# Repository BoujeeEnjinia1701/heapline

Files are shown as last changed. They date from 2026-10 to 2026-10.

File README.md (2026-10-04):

# HeapLine

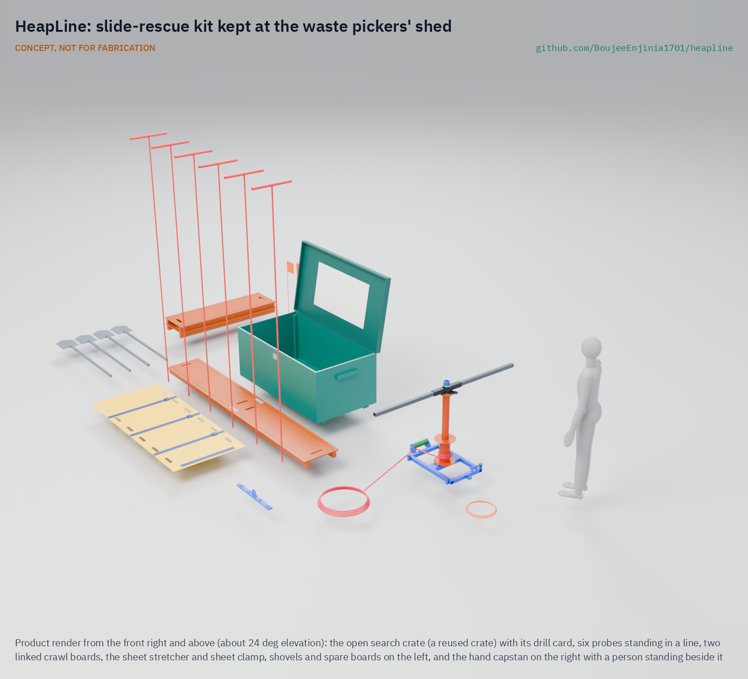
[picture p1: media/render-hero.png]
HeapLine: slide-rescue kit kept at the waste pickers' shed


     

**Area:** Situational field hardware · **TRL:** 3 of 9 (proof of concept on paper; constructable design) · **Value-engineering target:** USD 1,800; estimated parts cost USD 1,374 for the host site (USD 827 for each other site) · **Difficulty:** 3 of 5

Keeps a slide-rescue kit at the pickers' shed so they can search, probe and dig safely in the first minutes.

> CONCEPT, NOT FOR FABRICATION. HeapLine is a TRL 3 design on paper: it has not been built or tested.

## Concept rationale

HeapLine is a slide-rescue kit kept in a locked box at the waste pickers' shed or cooperative office. It holds probes, crawl boards, shovels, a hand capstan and a sheet stretcher. After a slide, pickers carry it out, post a lookout on the slope above, probe along the likely burial line, dig from crawl boards so they do not sink or trigger another slide, and move casualties out on the stretcher. A plain stop rule, printed on the lid, tells everyone when to pull back.

The model is companion rescue in avalanches, where survivors on the spot search at once rather than waiting for help, because survival falls quickly with burial time. The kit is cheap and made from common materials so cooperatives, municipalities and NGOs can stock every site. It is published as an open engineering reference, not certified rescue equipment, and it never replaces making the dumpsite itself safe.

## Burning platform

Dumpsite slides kill people who live and work on and beside the waste. The March 2017 landslide at Koshe in Addis Ababa killed 116 people ([UN-Habitat, 2019](https://unhabitat.org/news/05-jul-2019/after-the-tragic-landslide-that-killed-116-koshe-landfill-in-addis-ababa-is-safer)), at a site where 500 to 600 waste pickers worked every day ([IDS, 2017](https://www.ids.ac.uk/opinions/recognise-informal-waste-pickers-to-avoid-future-disasters-like-koshe/)). On 9 August 2024, after heavy rain, the Kiteezi landfill in Kampala collapsed onto homes; 35 bodies had been recovered by 16 August ([Wikipedia](https://en.wikipedia.org/wiki/Kiteezi_Landfill)), dozens were still missing and about 1,000 people were displaced ([StrongMinds](https://strongminds.org/kiteezi-landslide-highlights-urgent-need-for-mental-health-care-in-climate-disaster-responses/)). About 800 to 1,000 people scavenged at Kiteezi ([Wikipedia](https://en.wikipedia.org/wiki/Kiteezi_Landfill)).

These are not isolated events: the same account of Kiteezi lists failures at Naucalpan in Mexico in 2023, Meethotamulla in Sri Lanka and Koshe in 2017, and Guatemala City in 2008 ([Eos Landslide Blog, 2024](https://eos.org/thelandslideblog/kiteezi-1)). More than 15 million people are reported to live and work in communities that depend on dumpsites, and that is thought to be an underestimate ([International Samaritan, citing ISWA](https://intsam.org/about-garbage-dump-communities/)). Reporting on Kiteezi described rescue efforts as rudimentary ([The Independent, Uganda, 2024](https://www.independent.co.ug/cover-story-lets-not-waste-kiteezi-garbage-tragedy/)).

## Where it could be used

### By industry

| Industry | Use |
| --- | --- |
| Informal waste picking and recycling cooperatives | Kit and drill kept at the shed for the first minutes after a slide |
| Municipal solid waste management | A low-cost emergency measure for open dumps awaiting closure or rehabilitation |
| Disaster risk reduction and civil protection | Community first-responder training for dumpsite neighbourhoods |
| Humanitarian and development NGOs | Stocking kits and training at sites where people live on or beside waste |
| Small quarries, spoil heaps and mine waste | The same probe, board and dig method on other unstable heaps |

### By country or region

| Country or region | Why it matters there |
| --- | --- |
| Ethiopia | The 2017 Koshe landslide killed 116 people ([UN-Habitat, 2019](https://unhabitat.org/news/05-jul-2019/after-the-tragic-landslide-that-killed-116-koshe-landfill-in-addis-ababa-is-safer)). |
| Uganda | The 2024 Kiteezi collapse killed at least 35 people and displaced about 1,000 ([StrongMinds](https://strongminds.org/kiteezi-landslide-highlights-urgent-need-for-mental-health-care-in-climate-disaster-responses/)). |
| Sri Lanka and Mexico | Dumpsite landslides at Meethotamulla (2017) and Naucalpan (2023) show the hazard outside Africa ([Eos Landslide Blog, 2024](https://eos.org/thelandslideblog/kiteezi-1)). |
| Guatemala | A dumpsite failure in Guatemala City in 2008 ([Eos](https://eos.org/thelandslideblog/kiteezi-1)), at a site where about 2,000 recyclers work ([International Samaritan](https://intsam.org/about-garbage-dump-communities/)). |
| Jamaica | About 3,000 recyclers work at the Riverton City dump in Kingston ([International Samaritan](https://intsam.org/about-garbage-dump-communities/)). |

## What sparked the idea

The spark was the Kiteezi collapse in Kampala on 9 August 2024. After heavy rain the waste slope failed onto homes, killing at least 35 people, with dozens more missing ([StrongMinds](https://strongminds.org/kiteezi-landslide-highlights-urgent-need-for-mental-health-care-in-climate-disaster-responses/)), and coverage described rescue efforts as rudimentary ([The Independent, Uganda, 2024](https://www.independent.co.ug/cover-story-lets-not-waste-kiteezi-garbage-tragedy/)). A 2021 study had already recommended closing the site ([Eos Landslide Blog](https://eos.org/thelandslideblog/kiteezi-1)). The people closest to the victims were neighbours and pickers who knew the site, and they had nothing to dig with that was safer than their hands.

## Problem

When a dumpsite slope fails, waste pickers and neighbours are the first on the scene and start digging with their hands, on unstable waste, with no tools and no plan. They need a simple rescue kit and drill kept on site for the first minutes.

Full problem statement: [docs/01-problem.md](docs/01-problem.md)

## Concept

A slide-rescue kit kept at the waste pickers' shed (probes, crawl boards, shovels, capstan and sheet stretcher); after a dumpsite slide, pickers carry it out, probe and dig for buried people in the first minutes under a lookout and a clear stop rule.

Full design precis: [docs/02-concept.md](docs/02-concept.md) · Requirements: [docs/03-requirements.md](docs/03-requirements.md) · Calculations: [docs/04-calcs/01-sizing.md](docs/04-calcs/01-sizing.md) · Prototype build plan: [docs/05-build-plan.md](docs/05-build-plan.md) · Design decisions: [docs/06-design-decisions.md](docs/06-design-decisions.md) · 3D viewer: [media/viewer.html](media/viewer.html)

On paper (HPL-CAL-001): the first probe line starts about 4.6 minutes after the alarm; the hand capstan pulls 5 kN with four people at 114 N each, and a shear pin caps the rope at about 6.4 kN; with 18 mm probe tips, one person reaches 2.6 m in loosened debris and two people in stiffer debris; crawl boards sink 44 mm under a kneeling searcher. Following Amish's decisions of 2026-10-03, four people haul the stretcher on debris, the kit goes out in two waves of about 22 kg a person, and one capstan set is shared by neighbouring sites, so each site's search kit costs USD 827 against the restated USD 850 (R9). How far apart sharing sites may be is open in [docs/06-design-decisions.md](docs/06-design-decisions.md).

## Key components

- Search crate: a reused timber crate refitted on skids at every site, combination padlock, drill card and stop rule on the lid; the shared capstan set has its own crate at the host site
- Probes: six, each three 1 m steel sections on spigots with a blunt 18 mm tip
- Crawl boards: four plywood boards on battens, linked end to end
- Shovels: four, long handled
- Hand capstan: pumped friction capstan with a drive ratchet, two holding pawls and a shear pin; 14 mm rope, sling to a sound anchor, sheet clamp
- Sheet stretcher: roll-up 2 mm HDPE sheet with straps
- Lookout kit: whistles, vests, marker wands, safe-zone sign
- Lighting and PPE: AA head lamps (no lithium cells); gloves, boots, masks and glasses from the cooperative's stock

## Building the prototype

The build plan takes a capable maker from plywood, steel tube, plate and HDPE sheet to one complete site kit, with a making sketch for each of the sixteen made components, close-ups of the eleven joints that need one and fifteen illustrated steps. The boards and box are glued and screwed; the capstan, probes and clamp are cut, welded and profile cut; the rope, lifting gear, shovels and protective equipment are bought. It is a plan, not yet built; building and testing to it is TRL 4 work. See [docs/05-build-plan.md](docs/05-build-plan.md).

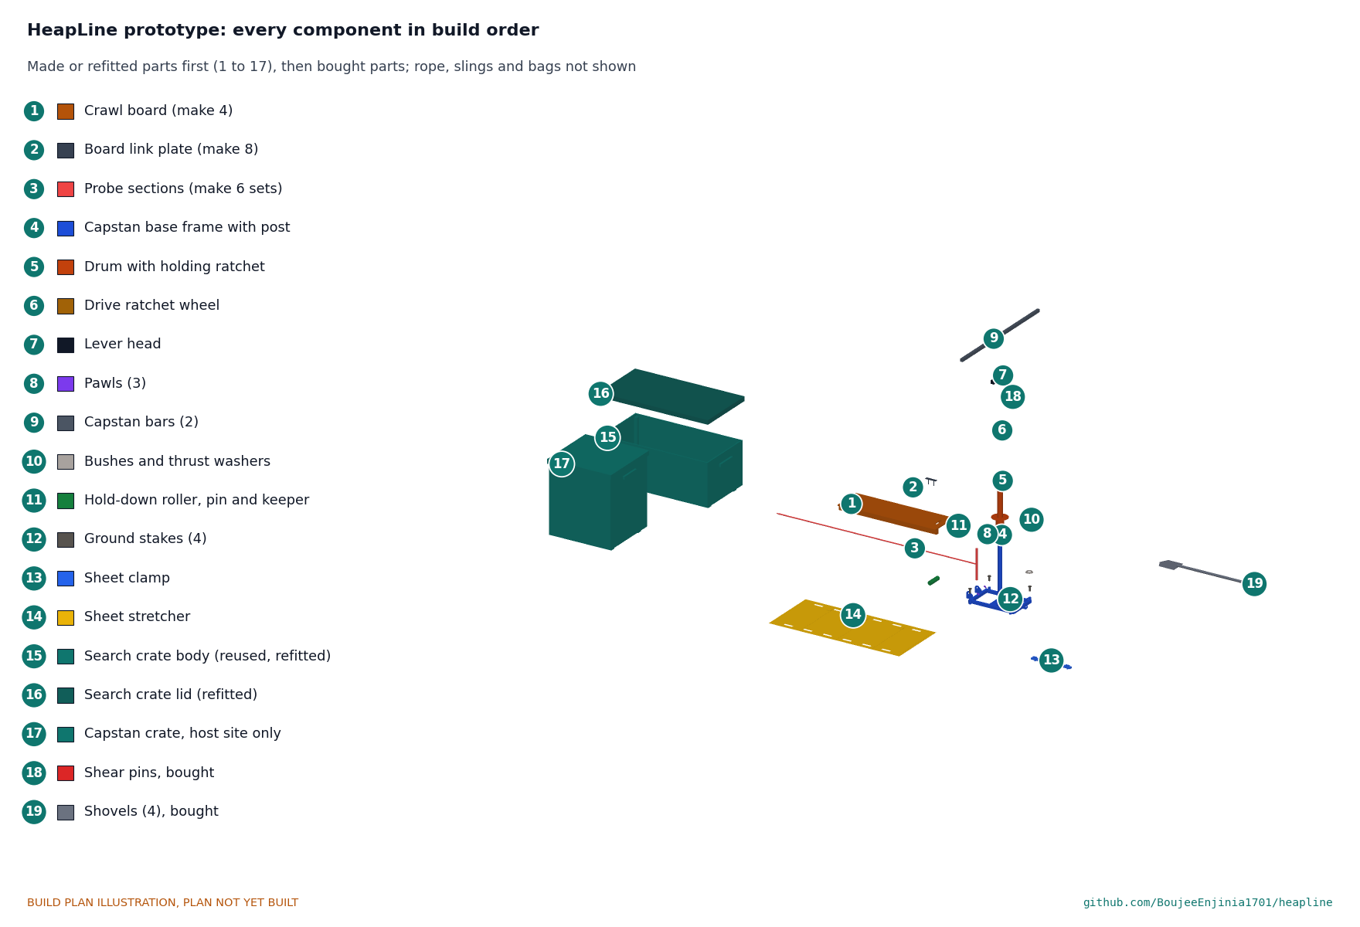
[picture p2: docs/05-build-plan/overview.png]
Every component of the prototype, pulled apart and numbered in build order


## Safety

> Rescue on unstable ground: published as an open engineering reference, not certified rescue equipment.
>
> A second slide can bury the rescuers. Never search without a lookout, and obey the stop rule every time.
>
> Call the fire service and emergency services at once; the kit is for the minutes before they arrive.
>
> Landfill gas can be flammable or toxic; no naked flames or smoking at the search.
>
> Sharp waste and infection risk: gloves and boots are part of the kit.
>
> The kit does not make a dumpsite safe; it must not be used to argue against closure or rehabilitation.
>
> The capstan rope stores energy: nobody in the line of a loaded rope, never lift or pull on a person, and fit only the specified 6 mm S275 shear pin.
>
> This design is published as an open engineering reference. It is not certified equipment.

## Repository layout

| Folder | Contents |
| --- | --- |
| `docs/` | Problem, concept, requirements, calculations and design decisions |
| `cad/src/` | build123d Python source, the source of truth for all geometry |
| `cad/step/`, `cad/stl/` | Exported models for FreeCAD, other CAD tools and printing |
| `cad/drawings/` | 2D sketches and dimensioned drawings |
| `bom/` | Bill of materials |
| `electronics/` | KiCad schematics and PCB layouts |
| `firmware/` | Microcontroller code |
| `media/` | Renders, perspectives and photos |
| `build-log/` | Dated prototyping notes |

## Documentation

Controlled documents follow the portfolio [documentation standard](.kit/STANDARDS.md). Each carries a document ID (HPL-PRC-001 for the precis), a version and a revision history. Branded PDFs are built with `python .kit/render.py` and attached to GitHub Releases when a document is tagged, for example `HPL-PRC-001/v1.0`.

## Credits

Designed by Amish Chadha at Design Molecule Labs. See [CONTRIBUTORS.md](CONTRIBUTORS.md) for roles. To cite this design, use [CITATION.cff](CITATION.cff) (GitHub shows it as "Cite this repository").

AI assistance (Claude) was used to accelerate prototype documentation and first-pass research. Design direction and all decisions are Amish Chadha's, recorded in this repository's decision records (`docs/decisions/`).

## Licenses

- **Hardware** (CAD, drawings, BOM, electronics): [CERN-OHL-S v2](LICENSE)
- **Software** (firmware, scripts, notebooks): [MIT](LICENSE-SOFTWARE)

A project of the [Design Molecule](https://designmolecule.com) lab.

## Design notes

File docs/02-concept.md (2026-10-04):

---
doc_id: HPL-PRC-001
title: HeapLine design precis
project: HeapLine
doc_type: Precis
version: "0.4"
status: Draft
date: '2026-10-03'
author: Amish Chadha
license: CERN-OHL-S-2.0
revisions:
- version: "0.1"
  date: '2026-09-30'
  author: Amish Chadha
  change: Initial scaffold
- version: "0.2"
  date: '2026-10-03'
  author: Amish Chadha
  change: TRL 2 precis; how it works, components, key design choices (HPL-DDR-001), first-order numbers, stop rule, safety
- version: "0.3"
  date: '2026-10-03'
  author: Amish Chadha
  change: TRL 3 figures from HPL-CAL-001 and the constructable design (HPL-DDR-002); pumped friction capstan with shear pin and holding pawls, sectional probes, linked crawl boards, enlarged site box
- version: "0.4"
  date: '2026-10-03'
  author: Amish Chadha
  change: "Amish's requirement decisions 20A, 21A, 22A and 23C (HPL-DDR-003): 18 mm probe tips; four haulers on debris; two carrying waves; reused search crate at every site, one capstan set shared by neighbouring sites, PPE from the cooperative"
---

# HeapLine design precis

Keeps a slide-rescue kit at the pickers' shed so they can search, probe and dig safely in the first minutes.

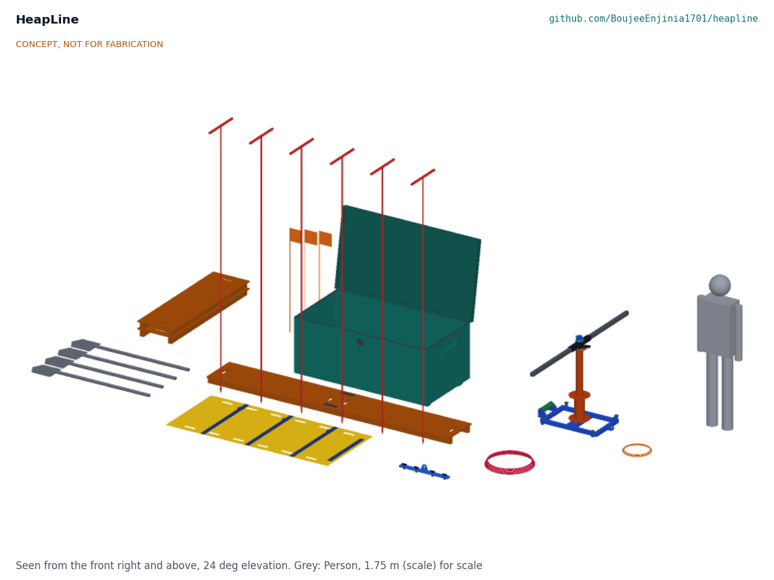
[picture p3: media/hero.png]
Figure 1. HeapLine kit laid out beside its search crate


*Figure 1. Concept render: the open search crate, six probes standing in a line, two linked crawl boards with the sheet stretcher and sheet clamp in front, shovels and spare boards on the left, and the hand capstan on the right with a 1.75 m person beside it.*

## Summary

HeapLine is a slide-rescue kit kept in a locked, reused crate at the waste pickers' shed. The search crate holds six sectional steel probes, four linked crawl boards, four shovels, a roll-up sheet stretcher, a lookout kit, lamps and the cooperative's protective equipment, with the drill card and stop rule printed on the lid. One hand capstan set, with its rope, anchor sling and sheet clamp, is shared by neighbouring sites and kept in its own crate at the host site. After a slide, four people carry the search kit out, post a lookout, lay boards onto the debris, probe in a line and dig from the boards; a second group of three brings the capstan to pull sheeting and timber off the dig from firm ground. On paper the first probe line starts 4.6 minutes after the alarm, the capstan gives 5 kN with four people at 114 N each, each site's search kit costs USD 827 and the shared capstan set USD 547 (HPL-CAL-001). It is an open engineering reference, not certified rescue equipment, and it never replaces making the dumpsite safe.

## How it works

1. **Alarm and lookout.** The first person at a slide raises the alarm and calls the fire service and emergency services. Someone runs to the shed, opens the combination padlock and hands out the search kit. Before anyone steps onto the debris, a lookout in a vest stands on stable ground to the side of the slide with a whistle and watches the slope above.
2. **Boards.** Searchers lay crawl boards from firm ground onto the debris and join them end to end with link plates. They kneel and walk only on the boards, which spread their weight and bridge voids.
3. **Probe line.** Up to six searchers stand on the boards about 0.5 m apart and push probes straight down, three 1 m sections joined on spigots, 2.6 m usable. A strike that feels soft and gives is marked with a flagged wand.
4. **Dig.** Searchers dig at each mark from the boards with long-handled shovels, from the downslope side, keeping a board between them and the hole's edge.
5. **Capstan.** Where sheeting, timber or heavy debris lies over a mark, a second group of three, who have brought the capstan set from the host site, sets the capstan on firm ground, stakes it and slings it to a sound tree, vehicle or column. The sheet clamp or a choker sling goes on the load, the rope runs to the capstan, and four people pump the two bars through quarter turns while a fifth tails the rope. Two pawls hold the drum whenever the bars stop; a 6 mm shear pin releases at about 6.4 kN so the rope, the capstan and the anchor are never overloaded. The capstan only pulls loads sideways away from the dig; it never lifts and never pulls on a person.
6. **Move the casualty.** The casualty is slid onto the sheet stretcher, strapped, and pulled back along the boards to a pickup point on firm ground: four haulers whenever it crosses debris, two only along the boards.
7. **Stop rule.** On any stop signal everyone leaves the debris along the boards to the marked safe zone, to the side of the slide path and never below it, and waits for the lookout's all clear or for the formal responders.

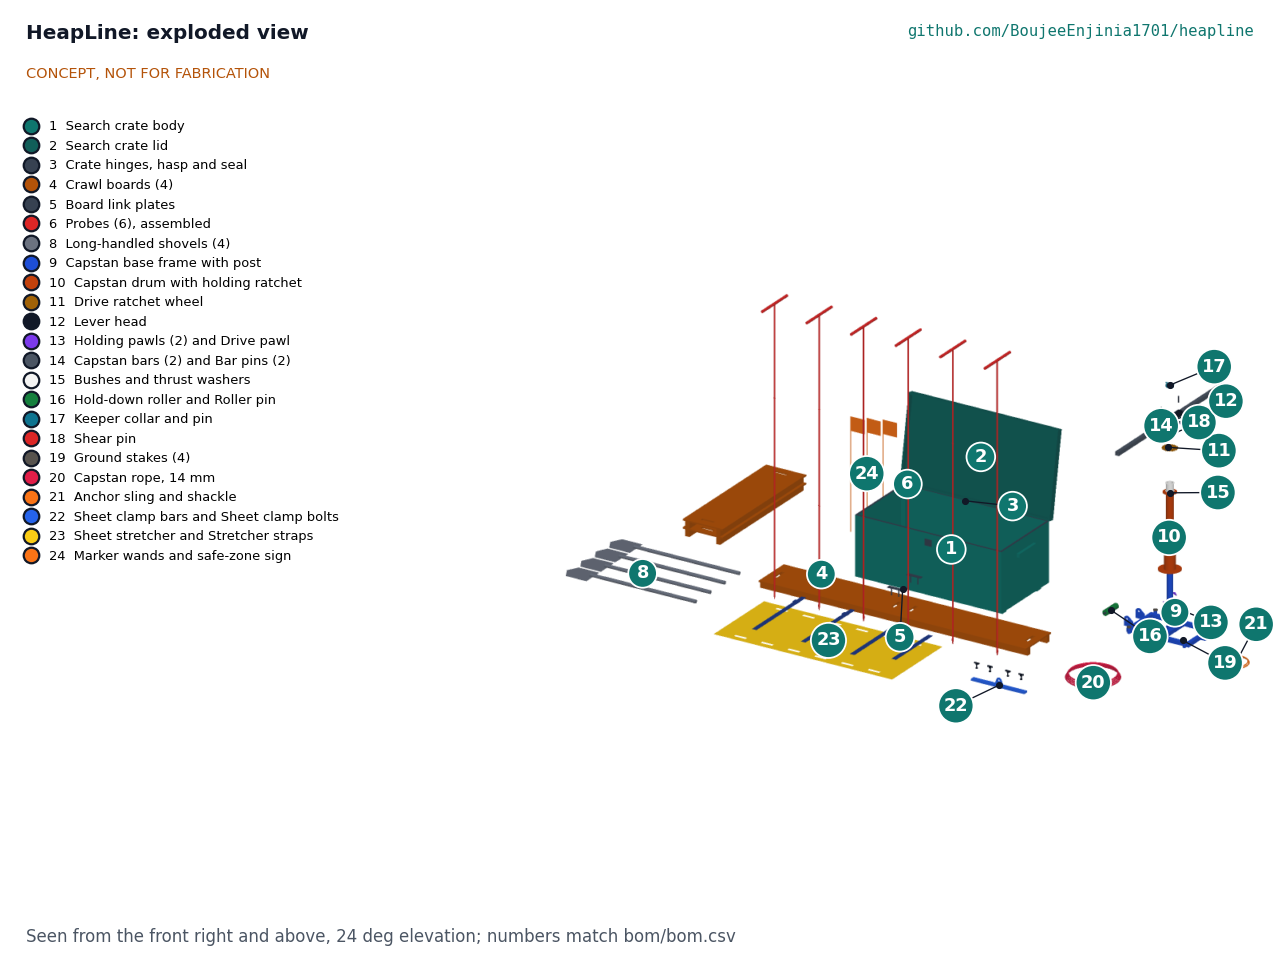
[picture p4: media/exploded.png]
Figure 2. Exploded view with BOM callouts


*Figure 2. Exploded view; the capstan parts are lifted off their post. Numbers are bill of materials lines.*

## Components

*Table 1. Main components (line numbers from `bom/bom.csv`).*

| BOM | Component | What it is |
| --- | --- | --- |
| 1, 2, 3 | Search crate | A reused timber crate (or bought job box), outside about 1640 x 860 x 640 mm, refitted on skids with a skirted lid over a seal, three strap hinges, hasp and combination padlock; stays at the shed |
| 31 | Capstan crate | A second reused crate at the host site only, outside about 940 x 900 x 1060 mm, for the shared capstan set |
| 4, 5 | Crawl boards | Four 1500 x 450 mm boards, 15 mm plywood on two 45 x 70 mm battens, 9.7 kg each; joined by link plates with two 12 mm pins |
| 6, 7 | Probes | Six probes, each three 1 m sections of 16 x 2.0 mm steel tube on spigots with R-clips, an 18 mm tip rounded to 3 mm and a 450 mm T handle; 3.07 m, 3.07 kg |
| 8 | Shovels | Four long-handled round-point shovels |
| 9 to 18 | Hand capstan | Base frame with a fixed post; drum turning on acetal bushes with a 24-tooth holding ring and two pawls; drive ratchet joined to the drum only by the 6 mm shear pin; lever head with a drive pawl and two bar sockets; two 900 mm bars; hold-down roller; keeper collar |
| 19 | Stakes | Four 25 mm stakes and a club hammer; they stop the frame turning, they are not the anchor |
| 20, 21 | Rope and lifting gear | 30 m of 14 mm polyester double braid (40 kN); two 2,000 kg round slings and three shackles |
| 22 | Sheet clamp | Two 50 x 8 mm flats with four wing bolts and a shackle lug; grips plastic sheeting |
| 23 | Sheet stretcher | 2 mm HDPE sheet 2000 x 900 mm with hand slots and three straps; rolls to 250 mm |
| 24 to 27 | Lookout kit, lighting, PPE, drill card | Whistles, vests, marker wands, safe-zone sign; AA lamps; gloves, boots, masks, glasses from the cooperative's stock; drill card and stop rule on the lid |

## Key design choices

Decided under Amish's pre-approvals of 2026-10-03 (HPL-DDR-001 and HPL-DDR-002) and by his requirement decisions of 2026-10-03 (HPL-DDR-003):

- **A pumped friction capstan.** The crew stands still and pumps two bars through a quarter turn; a drive ratchet turns the drum and two holding pawls keep it from running back. Nobody walks round it or steps over a rope at knee height, and the rope leaves under a roller 38 mm above the ground, level with the anchor sling, so it cannot tip.
- **A shear pin as the weakest link.** The rope, capstan, slings and anchor are all sized on 8 kN; the pin releases between 5.1 and 7.6 kN.
- **Sound anchors only.** A round sling to a tree, a parked vehicle or a structural column; never waste, never stakes alone. No sound anchor, no capstan.
- **Push, never drive, the probes.** A blunt tip and no hammer, so a probe cannot injure a buried person.
- **No lithium cells and no gas detector in the box.** Both would need upkeep the kit cannot assume; the rules cover the gap.
- **Everything packs.** The search crate and the capstan crate are sized so every item fits without clashes, the capstan standing assembled with its bars off (checked in the model).
- **A small, blunt probe tip.** 18 mm, 1 mm proud of the tube each side, so two people reach full depth in stiffer debris.
- **Two waves and four haulers.** The search kit goes first and the capstan second; four people haul the stretcher on debris, two only along the boards.
- **One capstan for neighbouring sites.** The costliest block is shared, and PPE comes from the cooperative's stock.

## First-order numbers

From HPL-CAL-001, on the constructable design:

*Table 2. First-order numbers.*

| Quantity | Value | Assumption |
| --- | --- | --- |
| Time from alarm to first probe line | 4.6 min | 100 m each way; 0.8 m/s carrying |
| Probe reach, 18 mm tip | 2.6 m in loosened debris; 2.6 m with two people in stiffer debris | Cone 0.4 or 1.0 MPa; sleeve 1 or 3 kPa |
| Board sinkage | 44 mm | 100 kg x 1.5 on very loose debris |
| Capstan force per person at 5 kN | 114 N | Four people, two on each bar |
| Shear pin release | 6.4 kN (5.1 to 7.6 kN) | S275 pin, plus or minus 20 % |
| Haul force on the stretcher, level debris | 510 N | Friction 0.5 |
| Heaviest carried item | 21.2 kg | Capstan frame with post |
| Carried kit | 151 kg in two waves | Search wave 21.5 kg each for four; capstan wave 21.7 kg each for three |
| Parts cost | USD 827 a site; shared capstan set USD 547 | R9 restated to USD 850 a site; value-engineering target USD 1,800 |

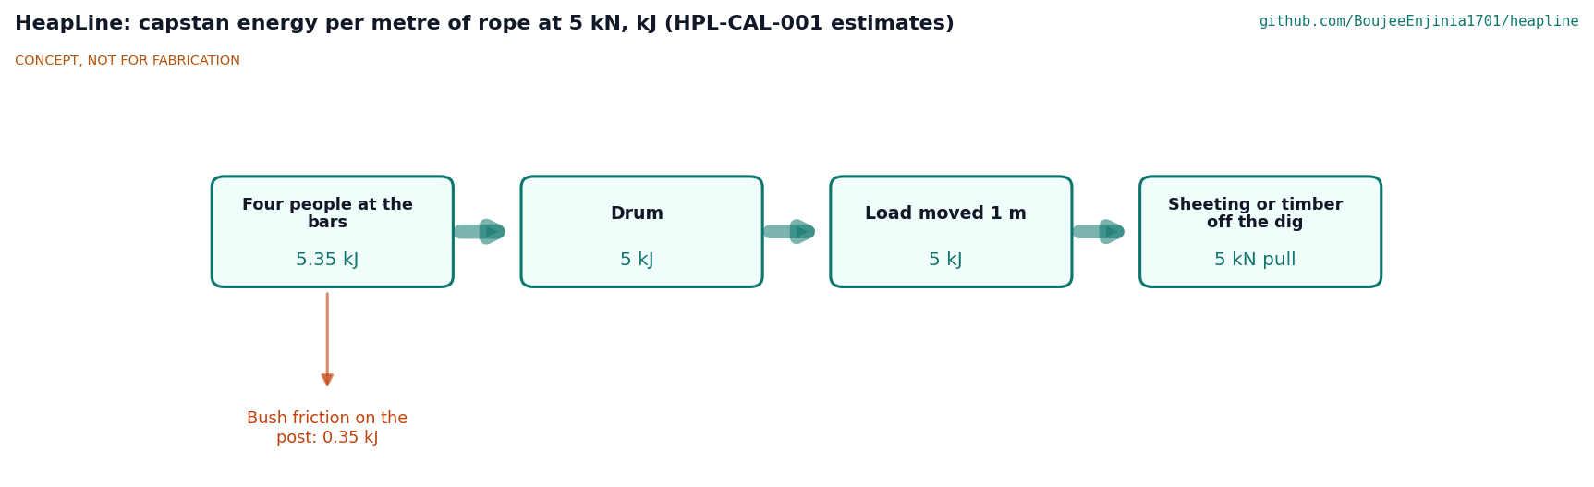
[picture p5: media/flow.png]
Figure 3. Capstan energy flow


*Figure 3. Energy per metre of rope at 5 kN (estimates from HPL-CAL-001).*

## Stop rule

Any one of these sends everyone off the debris along the boards to the safe zone at once:

1. The lookout's long whistle.
2. New cracks, bulging or movement on the slope above.
3. Water or mud flowing out of the debris.
4. Rain getting heavier.
5. A gas smell, smoke or hissing.
6. An order from the fire service, police or another formal responder.

## Patent design-arounds

From the preliminary patent, trademark and prior-art screen (not legal advice):

- Known collapse-rescue practice with no blocking patent found; publish dated drawings early as defensive disclosure.

## Shared blocks

- The SiltHaul hand capstan was considered and not used: it is limited to 2.5 kN and weighs about 48 kg (HPL-DDR-001, item 1).
- CalRig is the first candidate rig for the capstan proof loads and the shear pin release tests.

## Safety

> **Safety:** Rescue on unstable ground. HeapLine is published as an open engineering reference, not certified rescue equipment.
>
> A second slide can bury the rescuers. Never search without a lookout, and obey the stop rule every time.
>
> Call the fire service and emergency services at once; the kit is for the minutes before they arrive, and the search is handed over when they do.
>
> The capstan rope stores energy. Nobody stands in the line of a loaded rope or within 2 m of it; the capstan never lifts and never pulls on a person; only the specified 6 mm S275 shear pin is ever fitted; the tail is made fast on the cleat whenever hauling stops.
>
> Landfill gas can be flammable or toxic: no naked flames or smoking at the search.
>
> Sharp waste and infection risk: gloves and boots are part of the kit.
>
> The kit does not make a dumpsite safe; it must not be used to argue against closure or rehabilitation.

## Open questions

Decisions still open are kept in the design decisions register (`docs/06-design-decisions.md`).

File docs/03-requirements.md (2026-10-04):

---
doc_id: HPL-REQ-001
title: HeapLine requirements
project: HeapLine
doc_type: Requirements
version: "0.5"
status: Draft
date: '2026-10-04'
author: Amish Chadha
license: CERN-OHL-S-2.0
revisions:
- version: "0.1"
  date: '2026-09-30'
  author: Amish Chadha
  change: Initial scaffold
- version: "0.2"
  date: '2026-10-03'
  author: Amish Chadha
  change: TRL 2; concept status for each requirement; R10 (overload limit) and R11 (holds when let go) added under HPL-DDR-001
- version: "0.3"
  date: '2026-10-03'
  author: Amish Chadha
  change: TRL 3 results from HPL-CAL-001 on the constructable design (HPL-DDR-002); R2, R5 and R8 at risk and R9 not met, with decisions for Amish in docs/REVIEW.md
- version: "0.4"
  date: '2026-10-03'
  author: Amish Chadha
  change: "Amish's requirement decisions 20A, 21A, 22A and 23C (HPL-DDR-003): R2 met with the 18 mm tip; R5 met under the four-hauler rule; R8 met in two waves; R9 restated to USD 850 per site search kit with one capstan set shared by neighbouring sites"
- version: "0.5"
  date: '2026-10-04'
  author: Amish Chadha
  change: "Siting limit for a shared capstan set decided by Amish (round-3 decision 3A, HPL-DDR-004); targets and results unchanged"
---

# HeapLine requirements

Requirements for the site-kept slide-rescue kit. Targets are unchanged from the scaffold except R9, restated on 2026-10-03; R10 and R11 were added at TRL 2 (HPL-DDR-001). Results are paper estimates from HPL-CAL-001 v0.2 on the constructable design, not test results.

On 2026-10-03 Amish decided the four requirement decisions put to him at TRL 3 as recommended: "i agree with all the 46 recommendations you provided. please proceed." For HeapLine these are 20A (R2), 21A (R5), 22A (R8) and 23C (R9), recorded in HPL-DDR-003. On 2026-10-04 Amish decided option 3A on how far apart sites may share a capstan: "For round 3, I agree with all your proposed recommendations". A shared capstan serves only sites within about 500 m walk of the host shed (HPL-DDR-004); farther sites keep their own capstan set or rely on the search kit alone.

> **Safety:** HeapLine is used on unstable ground where a second slide can bury the searchers. It is published as an open engineering reference, not certified rescue equipment. The capstan stores energy in its rope; the overload limit (R10) and the holding pawls (R11) are safety requirements.

*Table 1. Requirements and their status at TRL 3.*

| ID | Requirement | Target | Verification (TRL 4 or later) | Result on paper (HPL-CAL-001) | Status |
| --- | --- | --- | --- | --- | --- |
| R1 | Deploy fast | Kit carried 100 m (330 ft) and first probe line started within 5 minutes of the alarm | Timed drills with the partner cooperative | 4.6 min estimated: run to the shed, open, carry the search wave back, post the lookout, lay boards while probes are joined | Met on paper |
| R2 | Probe depth | Probes reach at least 2.5 m (8.2 ft) into loose waste | Probe trials on a waste test heap, including whether the sleeve friction rises with the 18 mm tip's smaller clearance | 18 mm tip on all six probes (decision 20A). Loosened debris: 2.6 m (full usable depth) by one person. Stiffer debris: 2.6 m by two people, 0.6 m by one | Met on paper; confirm on a test heap at TRL 4 |
| R3 | Crawl board support | Board carries a 100 kg (220 lb) searcher with sinkage under 50 mm on loose fill | Load tests on representative fill | 44 mm on very loose debris with a 1.5 dynamic factor; bridges a 0.8 m void at 4.0 MPa in the battens | Met on paper |
| R4 | Capstan pull | At least 5 kN (1,124 lbf) pull from a hand capstan on a ground anchor | Pull test on CalRig | 5 kN with four people at 114 N each; the shear pin releases at about 6.4 kN (5.1 to 7.6 kN over a batch) | Met on paper |
| R5 | Casualty transport | Sheet stretcher moves a 100 kg (220 lb) casualty 30 m (98 ft) over debris with two to four haulers | Drill with manikin | Drill-card rule (decision 21A): four haulers on debris, 127 N each on level debris; two haulers only along the boards, 153 N each | Met on paper under the drill-card rule |
| R6 | Stop rule understood | All drill participants state the stop signals correctly after training | Post-drill check | Six stop signals printed on the lid and on pocket cards | Not verifiable at TRL 3 |
| R7 | Storage life | All items usable after 12 months stored in the site box | Annual inspection log at the pilot site | Exterior plywood, painted or galvanised steel, UV-stabilised HDPE, acetal, polyester; alkaline cells stored out of the lamps; no lithium cells | Met on paper by material choice |
| R8 | Portable | No single item over 25 kg (55 lb); whole kit carried by four people | Weighing; timed carry in two waves | Heaviest carried item 21.2 kg (capstan frame). Carried in two waves (decision 22A): four people carry the search kit first, 21.5 kg each; a second group of three brings the capstan set, 21.7 kg each | Met in two waves |
| R9 | Cost | Restated 2026-10-03 (decision 23C): parts at most USD 850 per site search kit, with one capstan set shared by neighbouring sites and costed per group, a reused crate (or bought job box) and PPE from the cooperative's stock. Was: parts under USD 400 per site kit | Costed bill of materials | USD 827 per site search kit; shared capstan set with its crate USD 547 per group (USD 274 a site if two share it) | Met as restated |
| R10 | Overload limit | Rope tension limited so the rope, capstan and anchor are never loaded past the 8 kN design tension | Shear pin release tests on a batch (TRL 4) | 6 mm S275 shear pin releases at 6.4 kN nominal, 7.6 kN at the top of the batch spread; rope factor 4.5 at 8 kN | Met on paper |
| R11 | Holds when let go | The drum cannot run back when the bars are released | Release test at working pull (TRL 4) | Two holding pawls on a 24-tooth ring; one pawl takes the design tension at 77 MPa tooth bearing | Met on paper |

## Assumptions

- Pickers and neighbours will organise a search in the first minutes if they have tools and a plan.
- Burial depths in the first minutes of a slide are within reach of hand probes and shovels in at least some cases.
- Sites or cooperatives can keep a box secure and inspected.
- Formal responders will welcome an organised community search rather than stop it.
- A sound anchor (a tree, a parked vehicle or a structural column) can be found on firm ground near most dumpsites; where none exists the capstan is not used.
- Debris resistance to probing has no published data for dumpsite slides; HPL-CAL-001 brackets it with a loosened and a stiffer case.
- Neighbouring sites that share one capstan set are close enough for its second wave to arrive while the search is still under way; a shared capstan serves only sites within about 500 m walk of the host shed (Amish, 2026-10-04, decision 3A: "For round 3, I agree with all your proposed recommendations"; HPL-DDR-004), checked in the TRL 4 timed drills.
- The cooperative keeps PPE in stock for the kit and replaces what is used.

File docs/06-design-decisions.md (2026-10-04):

---
doc_id: HPL-DEC-001
title: HeapLine design decisions register
project: HeapLine
doc_type: Design decisions register
version: "0.3"
status: Draft
date: '2026-10-04'
author: Amish Chadha
license: CERN-OHL-S-2.0
revisions:
- version: "0.1"
  date: '2026-10-03'
  author: Amish Chadha
  change: Register opened; design decisions made under Amish's pre-approvals of 2026-10-03; four requirement decisions proposed, awaiting Amish
- version: "0.2"
  date: '2026-10-03'
  author: Amish Chadha
  change: "Requirement decisions 20A, 21A, 22A and 23C made by Amish (HPL-DDR-003); one new open decision on how far apart sites sharing a capstan may be"
- version: "0.3"
  date: '2026-10-04'
  author: Amish Chadha
  change: "Open decision 1 decided by Amish (round-3 decision 3A, HPL-DDR-004) and moved to Decisions made; no open decisions"
---

# HeapLine design decisions register

Every design decision still to be made, and every decision made, in one place. Each decision is argued in full in its decision record under `docs/decisions/` or in `docs/REVIEW.md`; this register is the index Amish works from. The build plan (`docs/05-build-plan.md`) describes the design as it stands and does not list decisions.

> **Safety:** Several decisions below set HeapLine's safety case (lookout and stop rule, capstan overload limit, holding, anchors, what the capstan may pull, blunt probes, no lithium cells). Each took the conservative option; the evidence that would relax it is in HPL-DDR-001, Table 1.

## Open decisions

None. The four requirement decisions of 2026-10-03 and the siting limit for a shared capstan (decided 2026-10-04) are all under Decisions made.

## To confirm when parts are bought

| # | What to confirm | Why it matters | Source |
| --- | --- | --- | --- |
| 1 | Release load of the shear pins from the bar actually bought | The 6 mm pin is sized on 258 MPa shear; the lower end of its band must stay above 5 kN (R4) and the upper end below 8 kN (R10) | HPL-CAL-001, A4 |
| 2 | Breaking strength of the rope and its splice | Factor 4.5 at 8 kN assumes 40 kN and 90 % at the splice | HPL-CAL-001, A5 |
| 3 | Working load limits and pin sizes of the slings and shackles bought | The anchor eye's 22 mm hole is drilled for a 19 mm shackle pin | HPL-DWG-104 |
| 4 | Outside sizes of the tubes bought (60.3, 76.1, 88.9, 114.3) | The acetal bushes are turned to the bores | HPL-DWG-110 |
| 5 | Plywood thickness and the C16 grade of the battens | Board sinkage and void bridging assume 15 mm plywood on 45 x 70 C16 | HPL-CAL-001, C |
| 6 | Friction of the HDPE sheet bought on boards and mixed waste | The haul forces of R5 assume 0.3 and 0.5 | HPL-CAL-001, D |
| 7 | Sizes of the carry bags | The packing layout in HPL-DWG-002 uses their outer sizes | HPL-DWG-002 |
| 8 | Inside sizes and soundness of the reused crates found | The search crate must be at least 1604 x 824 x 622 mm inside and the capstan crate 904 x 864 x 1042 mm; a bought job box costs more | HPL-DWG-002; BOM lines 1 and 31 |

## Value engineering

Value-engineering target: USD 1,800 (a hypothetical control target, not a limit). Estimated cost of the constructable design: USD 1,374.00 (USD 426.00 under the target), for the host site, which keeps a search kit and the shared capstan set. Each other site's search kit costs USD 827.00, against the restated R9 target of USD 850 (HPL-DDR-003). Main cost drivers and savings worth trying:

- The shared capstan set (frame, drum, ratchets, head, pawls, bars, bushes, roller, keeper, pins, stakes, rope, slings, clamp and its crate) is USD 547, once per group of neighbouring sites.
- The search core (boards, links, probes, pins, shovels, stretcher, lookout kit and cards) is USD 526 a site.
- The reused search crate with its hardware is USD 98 a site; a bought steel job box would add about USD 200 to 500.
- Lighting is USD 95 a site; PPE comes from the cooperative's stock (about USD 168 if bought).
- Bought lifting gear (slings and shackles, USD 66) and the rope (USD 72) stay at rated grades because they carry the safety case.
- Savings worth trying: buying lamps in bulk across cooperatives; profile cutting the ratchets and pawls for several capstan sets at once; a local turner for the probe tips.

## Decisions made

| Date | Decision | Decided by | Record |
| --- | --- | --- | --- |
| 2026-10-03 | Vertical friction capstan pumped through a quarter turn with a drive ratchet, in place of the SiltHaul block or a walk-round capstan | Amish: "I pre-approve the batch runs along with any recommendations you come up with." and "Proceed with the remaining 15 scaffolds" | HPL-DDR-001, items 1, 14 |
| 2026-10-03 | 6 mm S275 shear pin limits the rope to about 6.4 kN; every part sized on 8 kN; R10 added | Amish, same pre-approvals | HPL-DDR-001, item 2 |
| 2026-10-03 | Two holding pawls on a ring at the drum's foot; tail made fast on a cleat when hauling stops; R11 added | Amish, same pre-approvals | HPL-DDR-001, item 3 |
| 2026-10-03 | Capstan anchored only by a sling to a sound tree, vehicle or column; stakes only against turning | Amish, same pre-approvals | HPL-DDR-001, item 4 |
| 2026-10-03 | 14 mm polyester double braid, 40 kN | Amish, same pre-approvals | HPL-DDR-001, item 5 |
| 2026-10-03 | The capstan pulls only sheeting, timber and debris sideways; never lifts, never pulls on a person | Amish, same pre-approvals | HPL-DDR-001, item 6 |
| 2026-10-03 | Sectional steel probes pushed by hand with a blunt tip; never driven | Amish, same pre-approvals | HPL-DDR-001, item 7 |
| 2026-10-03 | Plywood crawl boards on battens, linked end to end | Amish, same pre-approvals | HPL-DDR-001, item 8 |
| 2026-10-03 | Made HDPE sheet stretcher | Amish, same pre-approvals | HPL-DDR-001, item 9 |
| 2026-10-03 | AA alkaline lamps; no lithium cells in the box | Amish, same pre-approvals | HPL-DDR-001, item 10 |
| 2026-10-03 | No gas detector in the base kit; no flames; stop on any sign of gas | Amish, same pre-approvals | HPL-DDR-001, item 11 |
| 2026-10-03 | Six-signal stop rule; lookout posted before anyone steps onto debris; safe zone to the side | Amish, same pre-approvals | HPL-DDR-001, item 12 |
| 2026-10-03 | First co-design candidate to approach: Uganda Red Cross Society in Kampala with the Kiteezi waste pickers (not agreed) | Amish, same pre-approvals | HPL-DDR-001, item 13 |
| 2026-10-03 | CalRig as the first candidate rig for capstan proof loads and pin release tests | Amish, same pre-approvals | HPL-DDR-001, item 14 |
| 2026-10-03 | Combination padlock on the site box; monthly inspection log | Amish, same pre-approvals | HPL-DDR-001, item 15 |
| 2026-10-03 | `budget_usd` kept at 1,800 as a value-engineering target | Amish: "I also accept any cost overruns or variations from the assumed scope cost." | HPL-DDR-001, item 16 |
| 2026-10-03 | Design for construction: the fifteen changes of HPL-DDR-002 | Amish: "I pre-approve the batch runs along with any recommendations you come up with." and "Proceed with the remaining 15 scaffolds" | HPL-DDR-002 |
| 2026-10-03 | Appearance model additions for renders: rope turns on the drum, drill card on the lid, a mannequin beside the capstan | Amish, same pre-approvals | docs/REVIEW.md, TRL 3 |
| 2026-10-03 | R2: 18 mm probe tips on all six probes, confirmed on a test heap at TRL 4 (decision 20A) | Amish: "i agree with all the 46 recommendations you provided. please proceed." | [HPL-DDR-003](decisions/0003-requirement-decisions.md) |
| 2026-10-03 | R5: drill-card rule of four haulers on debris, two only along the boards (decision 21A) | Amish, same words | HPL-DDR-003 |
| 2026-10-03 | R8: the kit carried in two waves, the search kit first and the capstan set second (decision 22A) | Amish, same words | HPL-DDR-003 |
| 2026-10-03 | R9: one capstan set shared by neighbouring sites, a reused crate or bought job box, PPE from the cooperative's stock; R9 restated to USD 850 per site search kit (decision 23C) | Amish, same words | HPL-DDR-003 |
| 2026-10-04 | Open decision 1, R8 and R9 (3A): a shared capstan serves only sites within about 500 m walk of the host shed (capstan within about 15 min); farther sites keep their own capstan set or rely on the search kit alone; checked in the TRL 4 timed drills | Amish: "For round 3, I agree with all your proposed recommendations" | HPL-DDR-004 |

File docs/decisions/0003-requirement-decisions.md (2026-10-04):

---
doc_id: HPL-DDR-003
title: HeapLine requirement decisions (R2, R5, R8, R9)
project: HeapLine
doc_type: Design decision record
version: "0.1"
status: Draft
date: '2026-10-03'
author: Amish Chadha
license: CERN-OHL-S-2.0
revisions:
- version: "0.1"
  date: '2026-10-03'
  author: Amish Chadha
  change: Amish's requirement decisions 20A, 21A, 22A and 23C carried out
---

# 0003: Requirement decisions on probe depth, casualty transport, carrying and cost

- **Date:** 2026-10-03
- **Status:** accepted
- **Decided by:** Amish Chadha, 2026-10-03, accepting every recommendation put to him in the second round of requirement decisions: "i agree with all the 46 recommendations you provided. please proceed." For HeapLine: 20A (R2), 21A (R5), 22A (R8) and 23C (R9).

> **Safety:** The 18 mm tip stays blunt, with a 3 mm rounded point, and probes are still never driven. The four-hauler rule keeps each hauler within a sustainable pull on loose debris, so a casualty is not dropped or dragged in jerks. Sharing the capstan changes only when it arrives; the capstan is never needed for the first probe line, and the rules on anchors, the shear pin and the rope line are unchanged.

## Context

At TRL 3 (HPL-CAL-001 v0.1) four requirements were at risk or not met on paper: R2, because two people reached only 1.8 m with the 22 mm tip in stiffer debris; R5, because two haulers on loose debris need 255 N each; R8, because the whole 151 kg kit is 37.8 kg each for four people in one trip; and R9, because the kit cost USD 1,599 against USD 400. Each was put to Amish as state, options and a recommendation in `docs/REVIEW.md`.

## Options considered

- **R2 (decision 20):** A (chosen): 18 mm tip on all six probes. B: three probes with each tip. C: keep 22 mm and measure first.
- **R5 (decision 21):** A (chosen): drill-card rule, four haulers on debris, two only along the boards. B: a haul line with shoulder loops. C: both.
- **R8 (decision 22):** A (chosen): two waves, the search kit first and the capstan set second. B: lighter boards. C: a handcart.
- **R9 (decision 23):** A: share one capstan set. B: reused crate or bought job box, and PPE from the cooperative. C (chosen): both, and restate the target.

## Decision

1. **20A.** Every probe tip is turned from 18 mm bar (35 mm cone to a 3 mm rounded point, 20 mm parallel, 30 mm spigot); BOM line 6, HPL-DWG-103, Figure 7.
2. **21A.** The drill card (BOM line 27) and the build plan say: four people haul the stretcher whenever it crosses debris; two may haul it only along the boards.
3. **22A.** The drill card and the build plan say: four people carry the search kit first; a second group of three brings the capstan set.
4. **23C.** Every site keeps its search kit in a reused timber crate (or a bought steel job box where none can be had), at least 1604 x 824 x 622 mm inside (BOM lines 1 to 3). One capstan set is shared by neighbouring sites and kept at the host site in its own reused crate, at least 904 x 864 x 1042 mm inside (BOM line 31). The PPE comes from the cooperative's own stock (BOM line 26, no cost to the kit). R9 is restated as "parts at most USD 850 per site search kit, with one capstan set shared by neighbouring sites and costed per group" (HPL-REQ-001 v0.4).

## Consequences

- R2: two people reach the full 2.6 m in stiffer debris and one person 0.6 m; one person still reaches 2.6 m in loosened debris (HPL-CAL-001 [B1c], [B1s]). Met on paper, provided the sleeve friction does not rise as the tip's clearance over the tube falls from 3 mm to 1 mm a side [B5]; the TRL 4 test heap confirms it. Each probe is 3.07 kg, about 0.03 kg lighter.
- R5: met under the rule: 127 N each for four haulers on level debris, 153 N each for two on the boards [D].
- R8: met in two waves: 21.5 kg each for four in the search wave, 21.7 kg each for three in the capstan wave; heaviest item 21.2 kg [F2b]. R1 unchanged at 4.6 min [F3].
- R9: USD 827 per site search kit against the restated USD 850 [G1, G2b]; the shared capstan set with its crate is USD 547 per group of sites, USD 274 a site if two share it [G1b]. A bought steel job box (about USD 300 to 600) in place of the reused crate would take a site over the restated target.
- Value-engineering target: USD 1,800. Estimated cost of the constructable design: USD 1,374 (USD 426 under the target), for the host site, which keeps a search kit and the shared capstan set [G3]. `budget_usd` unchanged.
- The capstan wave from the host site arrives 3.8 min after the alarm from 100 m and 14.8 min from 500 m [F4]. How far apart sharing sites may be is a new open decision for Amish in `docs/06-design-decisions.md`.
- Model: crates parametrised in `cad/src/model.py` (`box`, `cap_box`), `packed_capstan()` added; checks cover both crates (no overlaps between packed items or with the crate, every item inside its crate). STEP and STL regenerated, with `heapline-capbox.step` and `.stl` added. HPL-DWG-002 Rev P3.

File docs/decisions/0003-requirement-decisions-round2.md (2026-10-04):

---
doc_id: HPL-DDR-003
title: HeapLine requirement decisions, round 2
project: HeapLine
doc_type: Design decision record
version: "0.1"
status: Draft
date: '2026-10-03'
author: Amish Chadha
license: CERN-OHL-S-2.0
revisions:
- version: "0.1"
  date: '2026-10-03'
  author: Amish Chadha
  change: Four requirement decisions (R2, R5, R8, R9) decided by Amish on 2026-10-03 as recommended, and carried into the design
---

# 0003: Requirement decisions, round 2

- **Date:** 2026-10-03
- **Status:** Decided
- **Decided by:** Amish Chadha, 2026-10-03

## Context

The TRL 3 review (`docs/REVIEW.md`, Session 2026-10-03, TRL 3, Decisions for Amish) posed four requirements that were at risk or not met on paper as decisions for Amish, each with its state, options and a recommendation: R2 probe depth, R5 casualty transport, R8 portable and R9 cost. On 2026-10-03 Amish wrote: "i approve all of the 47 recommendations provided by you. Execute them." Each of the four is therefore decided as its recommendation, exactly as worded, and carried into the design at TRL 3 scope only: model, calculations, bill of materials, drawings, build plan and documents. Nothing here is built or tested; the conditions below are checked at TRL 4.

> **Safety:** None of the four decisions touches the capstan's safety case (shear pin, holding pawls, anchors). Decision 1 keeps the probe tip blunt and hand pushed; decision 2 keeps each hauler within a sustained pull; decision 4 moves PPE to the cooperative's stock, which is safe only if a full set stays in every box.

## Options considered

The options for each decision are set out in full in `docs/REVIEW.md` (Session 2026-10-03, TRL 3, Decisions for Amish, items 1 to 4). Table 1 lists the option chosen.

## Decision

*Table 1. Decisions of 2026-10-03.*

| # | Requirement | Option chosen | Effect (HPL-CAL-001 v0.2, paper estimates) | Condition |
| --- | --- | --- | --- | --- |
| 1 | R2, probe depth | A: 18 mm tip on all six probes | In stiffer debris two people reach the full 2.6 m (1.8 m before) and one person 0.6 m (could not start before); loosened debris unchanged at 2.6 m for one person. Tip force to start in stiff debris 254 N (380 N before). Probe 3.07 kg (3.10 kg before). No cost change. R2 met on paper | Holds only if the sleeve friction does not rise as the tip's clearance over the tube falls from 3 mm to 1 mm a side; confirmed on a test heap of mixed waste at TRL 4 |
| 2 | R5, casualty transport | A: drill card rule: four haulers on debris, two only along the boards | 127 N each for four on level debris; 153 N each for two along the boards; both within the 200 N sustained pull. No cost or mass. R5 met on paper | The boards are laid back to firm ground before a casualty is moved; the rule is printed on the drill card and practised in drills |
| 3 | R8, portable | A: two waves: four carry the search kit first, a second group of three brings the capstan set | Search wave 21.5 kg each for four; capstan wave 21.7 kg each for three; both under the 25 kg carry limit. R1 unchanged at 4.6 min, since the capstan is not needed for the first probe line. No cost or mass. R8 met on paper for each wave | Seven people in all; the capstan arrives after the first probe line. The R8 target text still says "whole kit carried by four people" (new question, `docs/06-design-decisions.md`) |
| 4 | R9, cost | C: one capstan set shared by neighbouring sites, and a reused crate (or bought steel job box) for the site box with PPE from the cooperative's own stock | Parts bought for each site USD 830.00 (USD 1,599.00 before): capstan set USD 449.00 per group of sites; box with hardware USD 101.00 (USD 253.00 before); PPE (USD 168.00 if new) from stock. With the capstan share: USD 1,279.00 a site unshared, USD 1,054.50 shared by two, USD 979.67 by three. R9 still not met against USD 400 | A sound crate with the inside size of the plywood box is found for each site, otherwise the plywood box is made (USD 152 more); the cooperative keeps a full PPE set in every box; the group of sites sharing the capstan and its distance are still to be set (new question) |

## Consequences

- `cad/src/model.py`: probe tip 18 mm. STEP and STL regenerated; constructability checks still report no overlaps and no floating parts.
- `docs/04-calcs/sizing.py` and `01-sizing.md` (HPL-CAL-001 v0.2), `results.csv`: R2, R5 and R8 met on paper; R9 not met; per-site cost basis added.
- `bom/bom.csv`: a `cost_basis` column (site, shared, stock); lines 1 and 2 as a reused crate refit (estimated allowances of USD 40 and USD 13); line 6 18 mm bar; line 26 from stock; line 27 carries the carry and haul rules.
- `HPL-DWG-002` Rev P3; `HPL-DWG-103`, `115` and `116` Rev P2; build plan pictures, concept media and `media/model.glb` regenerated.
- `docs/03-requirements.md` v0.4, `docs/02-concept.md` v0.4, `docs/05-build-plan.md` v0.2, `README.md` updated. R targets are not restated.
- `budget_usd` in `project.yaml` stays at 1,800, the value-engineering target set by Amish; the estimate falls to USD 830 a site plus the capstan share.
- New questions raised by these decisions are posed in `docs/REVIEW.md` and the design decisions register: the capstan sharing group, the R8 target wording, and the fallback where no reused crate is found.

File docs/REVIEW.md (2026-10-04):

# Review note: HeapLine

## Session 2026-10-03: TRL 3 (kit 1.7.0, /to-trl3 under Amish's pre-approvals, batch 2)

Amish, 2026-10-03: "start with the first 14 repos from the list of 29 projects. I pre-approve the batch runs along with any recommendations you come up with. I also accept any cost overruns or variations from the assumed scope cost." For this batch: "Proceed with the remaining 15 scaffolds", under the same pre-approval. Every design choice and recommendation in this session is therefore recorded as decided, dated 2026-10-03, in `docs/06-design-decisions.md`. Requirements that are not met or at risk are not decided: each is posed below as a decision for Amish (Amish, 2026-10-03: "A simple statement doesn't add value - ensure you are identifying a state and posing it as a clear recommendation for me to decide on."). Kit 1.7.0 was installed from the kit source; `.kit/PHASE.yaml` kept as installed.

### TRL 2

**What was done.**

- `docs/01-problem.md` (HPL-PRB-001 v0.2): first co-design candidate, safety note, open questions answered or carried to the first trials.
- `docs/03-requirements.md` (HPL-REQ-001 v0.2): concept status for each requirement; R10 (overload limit) and R11 (holds when let go) added.
- `docs/02-concept.md` (HPL-PRC-001 v0.2): how it works, components, key design choices, stop rule, safety.
- `docs/decisions/0001-trl2-review-decisions.md` (HPL-DDR-001): sixteen TRL 2 review items decided.

**Results.** A hand capstan of the SiltHaul type gives only 2.5 kN and weighs about 48 kg, so HeapLine needs its own capstan; a pumped vertical friction capstan gives 5 kN with four people. Probing depth in waste depends on how compact the debris is and has no published data.

**Requirements not met.** R9 (cost) was already far above USD 400 with a capstan in every kit; R2 was uncertain. Both carried to TRL 3.

**Decisions made under the pre-approvals.** HPL-DDR-001, items 1 to 16: pumped friction capstan; shear pin (R10); holding pawls and tail cleat (R11); sound anchors only; 14 mm rope; the capstan never lifts or pulls on a person; blunt hand-pushed probes; linked plywood boards; made HDPE stretcher; no lithium cells; no gas detector; six-signal stop rule with a lookout; Uganda Red Cross Society in Kampala with the Kiteezi pickers as first co-design candidate (not agreed); CalRig as first proof-load rig; combination padlock; budget kept.

**Safety concerns.** A second slide burying searchers; rope whip from an overloaded rope or a failed anchor; drum run-back; landfill gas; sharp waste and infection.

### TRL 3

**What was done.**

- `docs/04-calcs/01-sizing.md` and `docs/04-calcs/sizing.py` (HPL-CAL-001 v0.1), `docs/04-calcs/results.csv`.
- `cad/src/model.py`: parametric build123d model with constructability checks (no overlaps, no floating parts, every item packs in the closed site box); STEP and STL in `cad/step` and `cad/stl` (capstan, probe, board pair, box, stretcher, clamp; assembly STEP in the display layout).
- `cad/src/sheets.py`: HPL-DWG-001 (hand capstan GA) and HPL-DWG-002 (site box, packed arrangement), Rev P2.
- `bom/bom.csv`: 30 lines, all priced, with suppliers by type.
- `cad/src/concept_media.py`: `media/hero.png`, `exploded.png`, `flow.png`, `concept-blueprint.png` and `.pdf` (HPL-DWG-010), `model.glb` (coarse tessellation) and `viewer.html`. No cutaway; the capstan's inside is shown in the build plan joints.
- `docs/decisions/0002-design-for-construction.md` (HPL-DDR-002); `design_state: constructable`.
- `cad/src/build_plan_media.py`: overview, sixteen making sketches (HPL-DWG-101 to 116), eleven joint close-ups and fifteen step pictures; `docs/05-build-plan.md` (HPL-BLD-001) and `docs/06-design-decisions.md` (HPL-DEC-001).
- `cad/src/product_model.py` (`product_parts()`, `TITLE`, `RENDER_VIEWS` hero, exploded, detail); scenes exported to `/home/claude/renders/heapline`. Photoreal renders, captions and cards are made on Amish's Mac; the README already leads with `media/render-hero.png`.
- `docs/01-problem.md` v0.2, `docs/02-concept.md` v0.3, `docs/03-requirements.md` v0.3, `README.md`, `project.yaml` (trl 3, trl_target 3).

**Results (HPL-CAL-001).** First probe line 4.6 min after the alarm. Capstan: 5 kN with four people at 114 N each; shear pin releases at 6.4 kN (5.1 to 7.6 kN); every capstan part, the rope (factor 4.5), the slings and the anchor eye sized on 8 kN; post 63 MPa; one holding pawl takes the design tension. Probes 3.07 m, 3.1 kg. Boards 9.7 kg, 44 mm sinkage, bridge a 0.8 m void at 4.0 MPa. Stretcher 510 N on level debris. Heaviest carried item 21.2 kg; carried kit 151 kg; site box 104 kg (stays at the shed). Value-engineering target: USD 1,800. Estimated cost of the constructable design: USD 1,599.00 (USD 201.00 under the target).

**Requirements not met or at risk.** R2 and R8 at risk, R5 at risk with two haulers, R9 not met; each is set out under Decisions for Amish. R6 is not verifiable at TRL 3.

### Decisions for Amish

Each item below is proposed, awaiting Amish, and is listed as open in `docs/06-design-decisions.md`. Effects are paper estimates from HPL-CAL-001.

**1. R2, probe depth: at risk.**
State: in loosened debris one person reaches the full 2.6 m usable depth, but in stiffer debris one person cannot start a probe and two reach 1.8 m. Cause: the 22 mm tip needs 380 N to start in stiff debris, more than one person's push, and near the surface a two-person push is capped by the probe's buckling load (506 N with 3 m free).

| Option | Effect on R2 | Cost | Mass |
| --- | --- | --- | --- |
| A: 18 mm tip on all six probes | Stiff debris: two people reach 2.6 m, one 0.6 m; loosened debris unchanged, if sleeve friction does not rise with the smaller clearance | No change | About 0.03 kg less a probe |
| B: three probes with 22 mm tips, three with 18 mm | Half the line as A, half as now | No change | Negligible |
| C: keep the 22 mm tip; measure debris resistance on a test heap at TRL 4 before choosing | None now | Test heap time only | None |

**Recommendation: A**, the 18 mm tip on all six, confirmed on a test heap at TRL 4; it is the only option that reaches 2.5 m on paper in stiff debris at no cost.

**2. R5, casualty transport: met with four haulers, at risk with two.**
State: on level debris the stretcher needs 510 N: 127 N each for four haulers, but 255 N each for two. Cause: friction of about 0.5 between HDPE and loose waste.

| Option | Effect on R5 | Cost | Mass |
| --- | --- | --- | --- |
| A: drill card rule: four haulers on debris; two only along the boards (153 N each) | Met in both cases | None | None |
| B: add a 10 m haul line with two shoulder loops so two more people pull from firm ground | 127 N each for four | About USD 15 | About 0.8 kg |
| C: both | Met with margin | About USD 15 | About 0.8 kg |

**Recommendation: A**: it meets R5 with no new parts, because the boards are already laid back to firm ground.

**3. R8, portable: at risk.**
State: the heaviest carried item is 21.2 kg, but the carried kit is 151 kg, 37.8 kg each if four people carry it in one trip. Cause: the capstan set (65 kg with stakes, rope, slings and clamp) on top of an 86 kg search kit.

| Option | Effect on R8 | Cost | Mass |
| --- | --- | --- | --- |
| A: two waves: four carry the search kit first (21.5 kg each, the 4.6 min of R1); a second group of three brings the capstan set (about 22 kg each) | Met for each wave; the capstan arrives a few minutes later | None | None |
| B: lighter boards (12 mm plywood on 45 x 45 battens) | Carried kit about 141 kg, 35 kg each for four | About USD 8 less | About 10 kg less |
| C: a two-wheeled handcart for the box contents | Met on tracks; poor on rough waste | About USD 150 more | About 25 kg more |

**Recommendation: A**: the capstan is not needed for the first probe line, so a second wave costs nothing and keeps R1.

**4. R9, cost: not met.**
State: USD 1,599 per site kit, against the per-kit cost target in HPL-REQ-001. Cause: the capstan set (USD 449), the site box with hardware (USD 253) and PPE with lighting (USD 263) on top of a USD 526 search core.

| Option | Effect on R9 | Cost | Mass |
| --- | --- | --- | --- |
| A: one capstan set shared by neighbouring sites, kept at the largest shed | About USD 1,150 a site | USD 449 less a site | Capstan wave only where it is kept |
| B: a reused crate or bought steel job box for the site box, and PPE from the cooperative's own stock | About USD 1,280 a site | About USD 320 less | Box mass unchanged or less |
| C: both | About USD 830 a site | About USD 770 less | As A and B |

**Recommendation: C**: it more than halves the cost without removing any function at the slide; no option within the concept reaches the target, so R9 would remain not met at about USD 830.

### Decisions made under the pre-approvals

HPL-DDR-002, the fifteen design-for-construction changes (below); the appearance model additions (below). All in `docs/06-design-decisions.md`.

### Build plan findings (design changes made for construction, HPL-DDR-002)

1. Capstan base frame 700 x 440 in 40 x 40 x 3 tube with a 100 x 40 x 4 centre member.
2. Post passes through the centre member, welded at both faces.
3. Hold-down roller takes the rope down to 38 mm, level with a rear anchor eye: no tipping.
4. Drum and spindle turn on acetal bushes on the fixed post.
5. Lever head with two sockets and a drive pawl: pumped through a quarter turn, nobody walks round.
6. Shear pin placed between the drive ratchet and the drum's top flange.
7. Pawl noses and pivots placed so the pawls clear the teeth (checked).
8. Keeper collar and pin on the post top.
9. Stake tubes and headed stakes.
10. Tail cleat on the rear member.
11. Probe spigot joints with R-clips; blunt 22 mm tip.
12. Boards on battens with pinned link plates.
13. Site box enlarged to 1700 x 1020 x 1060 so everything packs, capstan upright (checked).
14. Sheet clamp added.
15. Stretcher slots and straps defined.

### Appearance model

`product_model.py` uses the `model.py` solids in the display layout (kit beside the open box). Additions not in `model.py`: four turns of rope on the drum with a lead to the coil, the drill card on the inside of the lid, and a 1.75 m mannequin (`mannequin()`, standing) beside the capstan, behind it as seen from the hero camera so it is never between the camera and the kit. Decided under the pre-approvals.

### Safety concerns

- A second slide can bury searchers; the lookout and the six-signal stop rule are the only protection, and R6 (understood under stress) can only be shown in drills.
- Rope whip: the shear pin bounds rope tension, but a pin replaced by a bolt removes the bound; stop 3 and stop 6 say so.
- The capstan's anchor depends on finding a sound tree, vehicle or column on firm ground; where there is none the capstan is not used.
- Pulling debris near a buried person can shift the debris onto them; the capstan pulls sideways away from the dig only.
- Probes must never be driven; the blunt tip and the no-hammer rule protect a buried person.
- Landfill gas, sharp waste and infection remain hazards the kit cannot remove.
- The kit must not be used to argue against closing or rehabilitating a dumpsite.

### Recommended next step

When the phase allows TRL 4: Amish's choices on the four decisions above; then build one kit, run the shear pin release and proof-load tests on CalRig, the board and probe trials on a test heap of mixed waste, and timed drills with the first co-design candidate.

## Session 2026-09-30: scaffolded

### What was done

- Repository created from kit 1.6.0 at TRL 1, target TRL 2.
- `docs/01-problem.md` (HPL-PRB-001 v0.1): problem with cited evidence, users, environment, constraints, prior work, open questions.
- `docs/02-concept.md` (HPL-PRC-001 v0.1): how it works, components, patent design-arounds, shared blocks, safety.
- `docs/03-requirements.md` (HPL-REQ-001 v0.1): 9 proposed requirements.
- `README.md` with concept rationale, burning platform, where it could be used, and what sparked the idea.

## 2026-10-03: photoreal renders

Rendered with Blender Cycles on Amish's Mac from `cad/src/product_model.py`; captioned with `.kit/photo_caption.py`; `media/card.png` and `media/social-preview.png` made with `.kit/cards.py`. Views: hero, exploded, detail. image_qc passes and `render.py --check` has no FAIL.

## 2026-10-03: Amish's requirement decisions carried out

Amish, 2026-10-03: "i agree with all the 46 recommendations you provided. please proceed." For HeapLine these are decisions 20A (R2), 21A (R5), 22A (R8) and 23C (R9), each as recommended in the TRL 3 section above. Recorded in `docs/decisions/0003-requirement-decisions.md` (HPL-DDR-003) and the register `docs/06-design-decisions.md` v0.2. Not committed or pushed (batch run).

### Changes

- **20A, R2.** Probe tip turned from 18 mm bar on all six probes (`cad/src/model.py` `probe_tip`); BOM line 6; HPL-DWG-103; joint 3 (Figure 7, now 1 mm proud of the tube each side).
- **21A, R5.** Drill-card rule: four haulers whenever the stretcher crosses debris, two only along the boards. In BOM line 27, `docs/05-build-plan.md` (section 3.17, Step 15, first checks) and `docs/02-concept.md`.
- **22A, R8.** Drill-card rule: four people carry the search kit first; a second group of three brings the capstan set. In BOM line 27, the build plan (section 3.17, Step 12) and the precis.
- **23C, R9.** The made plywood site box is replaced by a reused timber crate refitted on skids at every site (or a bought steel job box where none can be had), at least 1604 x 824 x 622 mm inside (BOM lines 1 to 3). One capstan set is shared by neighbouring sites and kept at the host site in a second reused crate, at least 904 x 864 x 1042 mm inside (new BOM line 31, USD 98). PPE comes from the cooperative's stock (BOM line 26, USD 0; about USD 168 if bought). R9 restated in `docs/03-requirements.md` v0.4 as "parts at most USD 850 per site search kit, with one capstan set shared by neighbouring sites and costed per group".
- **Model.** Crates parametrised (`box`, `cap_box`); `packed_contents()` now packs the search crate and new `packed_capstan()` packs the capstan crate; new checks: both crates' shells, no overlaps between packed items or with either crate, every packed item inside its crate. Checks report no overlaps and no floating parts. STEP and STL regenerated, with `heapline-capbox.step` and `.stl` added.
- **Calculations.** `docs/04-calcs/sizing.py` and `01-sizing.md` v0.2: [B1] to [B5] for the 18 mm tip, [F2b] two waves, [F4] capstan wave arrival by distance, [G1] to [G3] split costs; `results.csv` re-run.
- **Pictures.** HPL-DWG-002 Rev P3 (search crate and capstan crate, packed); making sketches HPL-DWG-103 (18 mm tip), HPL-DWG-115 and 116 (crate body and lid refit); overview (crates, capstan crate added), joint 3, joint 11 and Step 11 (both crates packed); concept media regenerated (hero, exploded, blueprint key figures, `model.glb`). HPL-DWG-001 (capstan GA) is unchanged and stays at Rev P2.
- **Text.** `docs/05-build-plan.md` v0.2 (sections 1, 2, 3.3, 3.15 to 3.17, Steps 11, 12 and 15, first checks, safety stop 8, tools), `docs/02-concept.md` v0.4, `README.md`, `project.yaml` trl_evidence.
- **Appearance model.** `cad/src/product_model.py` picks up the smaller search crate and the 18 mm tips from `model.py`; scenes re-exported to `/home/claude/renders/heapline`.

### New results (HPL-CAL-001 v0.2)

- R2: met on paper. Stiffer debris: two people reach 2.6 m (was 1.8 m), one person 0.6 m (was 0); loosened debris unchanged at 2.6 m for one. Depends on the sleeve friction not rising with the smaller clearance; confirm on a test heap at TRL 4.
- R5: met under the rule. 127 N each for four on level debris; 153 N each for two on the boards (sustained limit 200 N).
- R8: met in two waves. 21.5 kg each for four (search wave), 21.7 kg each for three (capstan wave); heaviest item 21.2 kg. R1 unchanged at 4.6 min.
- R9: met as restated. USD 827 per site search kit against USD 850 (USD 23 under). Shared capstan set with its crate USD 547 per group: USD 274 a site if two share it, USD 182 if three. A bought steel job box in place of the reused crate (about USD 300 to 600) would put a site over the restated target.
- Value-engineering target: USD 1,800. Estimated cost of the constructable design: USD 1,374 (USD 426 under the target), for the host site, which keeps a search kit and the shared capstan set. `budget_usd` unchanged.
- Masses: probe 3.07 kg (was 3.10); search crate about 53 kg body and 17 kg lid, capstan crate about 53 kg and 11 kg, as modelled in 18 mm boards (a reused crate's own mass will differ; neither is carried).

### For Amish

- **New open decision 1: how far apart sites sharing one capstan set may be.** State: the capstan wave from the host shed arrives 3.8 min after the alarm from 100 m, 9.2 min from 300 m, 14.8 min from 500 m and 28.5 min from 1 km (HPL-CAL-001 [F4]). Options: (a) share only within about 500 m walk of the host shed; farther sites keep their own capstan set or rely on the search kit alone; (b) share within about 1 km; (c) no limit, agreed site by site with the co-design partner. **Recommendation: (a)**, checked in the TRL 4 timed drills. Proposed, awaiting Amish.
- The photoreal renders (`media/render-*.png`), card and social preview still show the plywood site box and 22 mm tips; re-render on the Mac from the re-exported scenes.

### Safety

- The 18 mm tip keeps its 3 mm rounded point and probes are still never driven.
- The four-hauler rule keeps each hauler under the 200 N sustained pull on loose debris.
- Sharing the capstan only delays it; the anchor, shear pin, rope-line and stop rules are unchanged. PPE from the cooperative's stock must be checked at every monthly inspection (safety stop 8), since the kit no longer buys its own.

## 2026-10-04: Amish's requirement decisions carried out (round 3)

Amish on 2026-10-04: "For round 3, I agree with all your proposed recommendations". For HeapLine this decides open decision 1 of HPL-DEC-001 as recommended (3A). Recorded in `docs/decisions/0004-capstan-sharing-limit.md` (HPL-DDR-004). Wording and records only; no geometry. Not committed or pushed.

### Changes

- `docs/03-requirements.md` v0.5: siting limit stated in the decisions paragraph and assumptions; Amish quoted.
- `docs/04-calcs/01-sizing.md`: note on the capstan wave updated.
- `docs/05-build-plan.md` v0.3: siting sentence in section 1; new capstan wave drill row in the first checks.
- `docs/06-design-decisions.md` v0.3: open decision 1 moved to Decisions made; Open decisions now "None."
- No model, BOM, drawing or media change was needed.

### New results

- R8 and R9 unchanged: met as restated. A shared capstan serves only sites within about 500 m walk of the host shed (arrival about 14.8 min), checked in the TRL 4 timed drills.
- Value-engineering target: USD 1,800. Estimated cost of the constructable design: USD 1,374.00 (USD 426.00 under the target). Unchanged.

### For Amish

Nothing new.

## 2026-10-04: photoreal renders redone after the round-2 and round-3 decisions

Views: hero, exploded, detail; cards regenerated; image_qc passes and `render.py --check` has no FAIL.

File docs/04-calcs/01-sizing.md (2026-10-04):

---
doc_id: HPL-CAL-001
title: HeapLine sizing calculations
project: HeapLine
doc_type: Calculation
version: "0.2"
status: Draft
date: '2026-10-03'
author: Amish Chadha
license: CERN-OHL-S-2.0
revisions:
- version: "0.1"
  date: '2026-10-03'
  author: Amish Chadha
  change: First sizing note on the constructable design (HPL-DDR-002); capstan, probe, crawl board, stretcher, clamp, masses, deployment time and cost
- version: "0.2"
  date: '2026-10-03'
  author: Amish Chadha
  change: "Amish's requirement decisions 20A, 21A, 22A and 23C (HPL-DDR-003): 18 mm probe tip; four haulers on debris; two carrying waves; shared capstan set, reused crates and PPE from the cooperative; R9 restated"
---

# HeapLine sizing calculations

The constructable design meets R1, R3, R4, R10 and R11 on paper. After Amish's requirement decisions of 2026-10-03 (HPL-DDR-003; Amish: "i agree with all the 46 recommendations you provided. please proceed."), R2 (probe depth) is met on paper with the 18 mm tip, R5 (casualty transport) is met under the drill-card rule of four haulers on debris, R8 (portable) is met by carrying the kit in two waves, and R9 (cost) is met as restated, with one capstan set shared by neighbouring sites. Every figure below is printed by `docs/04-calcs/sizing.py` with the tag shown in brackets, from the geometry in `cad/src/model.py` and the prices in `bom/bom.csv`. These are first-principles estimates for a paper proof of concept, not test results.

> **Safety:** The capstan stores energy in a loaded rope. Every capstan part is sized on an 8 kN design tension, above the top of the shear pin's release band, and the rope, slings and anchor are chosen so the shear pin is always the weakest link. Searches take place on unstable ground; nothing here makes a dumpsite safe.

## Assumptions

*Table 1. Assumptions.*

| Quantity | Value | Basis |
| --- | --- | --- |
| Bush friction, acetal on painted steel | 0.15 | Dry or dusty; low-friction acetal would be about 0.1 |
| Rope friction on the drum | 0.20 | Polyester on painted steel, low side, so the tail force is not underestimated |
| Rope turns on the drum while hauling | 4 | Ship and rescue capstan practice |
| Shear pin material | S275 bar, ultimate shear 258 MPa (0.6 x 430 MPa) | Release spread taken as plus or minus 20 % over a batch |
| Design tension for every capstan part | 8,000 N | Above the top of the pin's release band (7,648 N) |
| Sustained push per person on a bar | 150 N | Short bouts; heaving can reach 300 to 400 N |
| Probe resistance, loosened debris | Cone 0.4 MPa, sleeve friction 1 kPa | No published data for dumpsite slides; a central case |
| Probe resistance, stiffer debris | Cone 1.0 MPa, sleeve friction 3 kPa | A compacted or wet case |
| Downward push on a probe | 350 N one person, 650 N two | Sustained, leaning on the T handle |
| Subgrade modulus of slide debris | 0.10 MN/m³ | Very loose, low side |
| Searcher on a board | 100 kg with a 1.5 dynamic factor | Kneeling and shifting weight |
| Timber battens | C16: 16 MPa bending, 8 GPa modulus | Treated softwood |
| Stretcher friction | 0.5 on debris, 0.3 on boards | HDPE on mixed waste and on plywood |
| Sustained pull per hauler | 200 N | Strap over the shoulder, 30 m |
| Carry limit per person | 25 kg | 100 m over rough ground |
| Walking speeds | 2.5 m/s running empty, 0.8 m/s carrying | Rough ground |
| Opening the capstan crate and sharing out its load | 60 s | Three people; estimate for the capstan wave from the host site |

## A. Hand capstan

The capstan meets R4 with four people, and its shear pin bounds the rope tension (R10).

- The rope runs at a 64.2 mm radius on the drum; friction in the foot bush adds the equivalent of 4.5 mm of lever per newton of rope tension [A1].
- A 5,000 N pull needs 343 N m at the head: 228 N at each bar end, so 114 N each for four people (two on each bar) or 228 N each for two, with hands 754 mm from the axis [A2].
- With four turns the tailer holds about 33 N on the tail [A3].
- The 6 mm S275 shear pin on a 60 mm radius releases at 7.29 kN, 438 N m, which is a rope tension of about 6,374 N, between 5,099 and 7,648 N over a batch [A4]. The lower bound stays above the 5 kN of R4.
- The 14 mm polyester rope (40 kN, 36 kN through the splice) has a factor of 7.2 at 5,000 N and 4.5 at the 8,000 N design tension [A5].
- The rope leaves the drum 15 degrees down to the hold-down roller. The post carries 0.70 kN m at 8,000 N: 63 MPa in the 60.3 x 5.0 tube against a 355 MPa yield [A6].
- One holding pawl alone takes 5.5 kN at the design tension: 77 MPa bearing on a 12 x 6 mm tooth face and 49 MPa shear in its 12 mm pin [A7]. The drive pawl takes 5.9 kN at pin release: 62 MPa on the 12 x 8 mm tooth face [A8].
- Each 40 x 40 x 2.5 bar carries 219 N m at its socket when the pin releases: 50 MPa [A9].
- Each quarter-turn stroke takes in about 101 mm of rope, about 1.5 m a minute at 15 strokes [A10].
- The rope leaves under the roller 38 mm above the ground and the anchor sling pulls from the eye at the same height, so there is no tipping moment; the stakes only stop the frame turning and skating [A11].
- The 10 mm anchor eye sees 42 MPa bearing from the 19 mm shackle pin at 8,000 N; the 2,000 kg round sling has a factor of 2.5 on its working load limit at the design tension [A12].

## B. Probes

R2 is met on paper with the 18 mm tip on all six probes (decision 20A): one person reaches the full depth in loosened debris and two people in stiffer debris. The sleeve friction assumption must be confirmed on a test heap at TRL 4.

- Loosened debris: tip 102 N, friction 50 N per metre, 227 N to push to 2.5 m; one person reaches the full 2.6 m usable depth [B1c].
- Stiffer debris: tip 254 N, friction 151 N per metre, 631 N to push to 2.5 m. Two people reach the full 2.6 m; one person reaches 0.6 m, because a single person's push is used up by the tip and the friction [B1s].
- The 16 x 2.0 tube buckles at 4,558 N with 1 m free, 1,139 N with 2 m free and 506 N with 3 m free (pinned ends) [B2-1, B2-2, B2-3].
- The probe is 3,068 mm long assembled and weighs 3.07 kg; the 18 mm tip has a 3 mm rounded point; usable depth is about 2.6 m with the handle at chest height above the surface [B3].
- For comparison, the earlier 22 mm tip let one person reach nothing in stiffer debris and two people 1.8 m [B4].
- The tip now stands 1 mm proud of the 16 mm tube each side, against 3 mm before. The results assume the sleeve friction does not rise as that clearance falls; the test heap at TRL 4 must confirm it [B5].

## C. Crawl boards

R3 is met on paper.

- A kneeling 100 kg searcher with a 1.5 dynamic factor, plus the 9.7 kg board, spread over 0.8 m of board gives 4.4 kPa and 44 mm of sinkage on very loose debris [C1].
- Bridging a 0.8 m void with 1,472 N at mid-span gives 294 N m; the battens alone see 4.0 MPa (factor 4.0 on C16) and deflect 0.8 mm [C2].
- The deck spans 300 mm clear between the battens; a 1,000 N knee on 150 mm of deck gives 13.3 MPa in 15 mm plywood [C3].
- Each board weighs 9.7 kg and each link plate 0.43 kg [C4].

## D. Sheet stretcher

R5 is met under the drill-card rule of decision 21A: four haulers whenever the stretcher crosses debris, two only along the boards (153 N each). Two haulers on loose debris would need 255 N each, more than the 200 N sustained pull assumed, which is why the rule exists.

*Table 2. Haul force for a 100 kg casualty on the 3.9 kg stretcher [D].*

| Surface | Total | Each of two haulers | Each of four haulers |
| --- | --- | --- | --- |
| Debris, level | 510 N | 255 N | 127 N |
| Debris, 15 degrees up | 756 N | 378 N | 189 N |
| Boards, level | 306 N | 153 N | 76 N |
| Boards, 15 degrees up | 559 N | 280 N | 140 N |

## E. Sheet clamp

Four M12 wing bolts at 2.5 kN each, with two faces at a friction coefficient of 0.3, hold about 6.0 kN before the sheet slips [E1]. That is below the shear pin's nominal release; a sheet that slips out of the clamp is safe.

## F. Masses, carrying and deployment

*Table 3. Carried items [F].*

| Item | Mass |
| --- | --- |
| Capstan frame with post and roller | 21.2 kg |
| Capstan drum, head and ratchet | 15.3 kg |
| Capstan bars (2) | 5.4 kg |
| Stakes and mallet | 10.0 kg |
| Rope (30 m) | 4.1 kg |
| Slings, shackles and sheet clamp | 7.6 kg |
| Crawl board (each of 4) | 9.7 kg |
| Board link plates (8) | 3.5 kg |
| Probes (6) | 18.4 kg |
| Shovels (4) | 9.2 kg |
| Sheet stretcher | 3.9 kg |
| Lookout kit, lighting, PPE, bags and cards | 13.5 kg |

- The heaviest carried item is the capstan frame with its post and roller, 21.2 kg. The search crate (about 53 kg body and 17 kg lid as modelled in 18 mm boards) stays at the shed; the capstan crate (about 53 kg and 11 kg) stays at the host site [F1]. A reused crate's own mass will differ.
- The carried kit is 151 kg: 86 kg for the search wave and 65 kg for the capstan wave. Four people carrying everything at once would take 37.7 kg each [F2].
- Two waves (decision 22A): four people carry the search wave first, 21.5 kg each; a second group of three brings the capstan set, 21.7 kg each, under the 25 kg limit. R8 is met in two waves [F2b].
- Deployment from the alarm to the first probe line: 40 s to run 100 m to the shed, 30 s to open, 125 s to carry back, 20 s to post the lookout and 60 s to lay the first boards while the probes are joined: 275 s, 4.6 min [F3]. The capstan is not needed for the first probe line, so R1 is unchanged.
- The capstan set is kept at the host site (decision 23C). Allowing 60 s to open its crate and share out the load, the capstan wave arrives 3.8 min after the alarm from 100 m, 9.2 min from 300 m, 14.8 min from 500 m and 28.5 min from 1 km [F4]. Amish decided on 2026-10-04 (3A, HPL-DDR-004) that a shared capstan serves only sites within about 500 m walk of the host shed, where it arrives in about 14.8 min; the TRL 4 timed drills check this.

Decision 23C splits the kit into a search kit that every site keeps and one capstan set shared by neighbouring sites, puts each in a reused crate (or a bought steel job box where none can be had), and takes the PPE from the cooperative's own stock.

- The search kit with its crate costs USD 827.00 per site: crate and hardware USD 98.00, lighting USD 95.00, PPE USD 0 from the cooperative's stock (about USD 168 if bought) [G1].
- The shared capstan set (capstan, rope, slings, clamp and its own crate) costs USD 547.00 for each group of neighbouring sites: USD 273.50 a site if two share it, USD 182.33 if three [G1b].
- The search core (boards, links, probes, pins, shovels, stretcher, lookout kit and cards) is USD 526.00 [G2].
- R9 as restated (HPL-REQ-001 v0.4): USD 827.00 per site search kit against USD 850, USD 23.00 under [G2b]. A bought steel job box in place of the reused crate (about USD 300 to 600) would put the site over the restated target.
- Value-engineering target: USD 1,800. Estimated cost of the constructable design: USD 1,374.00 (USD 426.00 under the target), for the host site: its search kit and the shared capstan set [G3].

## Results against the requirements

*Table 4. Results (also written to `docs/04-calcs/results.csv`).*

| ID | Result | Status |
| --- | --- | --- |
| R1 | 4.6 min estimated from alarm to first probe line | Met on paper |
| R2 | 18 mm tip: loosened debris 2.6 m by one person; stiffer debris 0.6 m for one, 2.6 m for two | Met on paper; confirm on a test heap at TRL 4 |
| R3 | 44 mm sinkage; bridges a 0.8 m void at 4.0 MPa | Met on paper |
| R4 | 5 kN at 114 N each for four people; pin releases at 5.1 to 7.6 kN | Met on paper |
| R5 | 127 N each for four on level debris; 153 N each for two on the boards | Met with the drill-card rule: four haulers on debris, two only along the boards |
| R6 | Stop rule printed on the lid and pocket cards | Not verifiable at TRL 3 |
| R7 | Weather-resistant materials; no lithium cells | Met on paper by material choice |
| R8 | Heaviest item 21.2 kg; search wave 21.5 kg each for four, capstan wave 21.7 kg each for three | Met in two waves |
| R9 | USD 827 per site search kit against USD 850; shared capstan set USD 547 per group of sites | Met as restated |
| R10 | Pin releases at 6.4 kN nominal, 7.6 kN at most; rope factor 4.5 at 8 kN | Met on paper |
| R11 | Two holding pawls; one takes the design tension | Met on paper |

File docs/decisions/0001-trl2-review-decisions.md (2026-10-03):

---
doc_id: HPL-DDR-001
title: HeapLine TRL 2 review decisions
project: HeapLine
doc_type: Design decision record
version: "0.1"
status: Draft
date: '2026-10-03'
author: Amish Chadha
license: CERN-OHL-S-2.0
revisions:
- version: "0.1"
  date: '2026-10-03'
  author: Amish Chadha
  change: TRL 2 review items decided under Amish's pre-approvals of 2026-10-03
---

# 0001: TRL 2 review decisions

- **Date:** 2026-10-03
- **Status:** accepted

## Context

The TRL 2 review (`docs/REVIEW.md`, TRL 2 section) raised the items below. On 2026-10-03 Amish wrote: "start with the first 14 repos from the list of 29 projects. I pre-approve the batch runs along with any recommendations you come up with. I also accept any cost overruns or variations from the assumed scope cost." For this second batch he added: "Proceed with the remaining 15 scaffolds", under the same pre-approval. Every design recommendation below is therefore decided as recommended. Choices that touch safety take the conservative option, with the evidence that would relax them stated. Partners are first candidates to approach, not agreements. Requirements that are not met or at risk are not decided here; they are posed to Amish in `docs/REVIEW.md` and the design decisions register.

> **Safety:** HeapLine is used on unstable ground where a second slide can bury the searchers, and its capstan stores energy in a loaded rope. Items 2, 3, 4, 6, 7, 10, 11 and 12 set its safety case.

## Options considered

Table 1 lists the options for each item and the one chosen.

## Decision

*Table 1. Items decided on 2026-10-03 under Amish's pre-approvals.*

| # | Item | Options | Decision | What would relax a safety choice |
| --- | --- | --- | --- | --- |
| 1 | Capstan type | (a) the SiltHaul split winding drum with chain drive; (b) a walk-round vertical capstan with bars; (c) a vertical friction capstan worked by pumping two bars through a quarter turn, with a drive ratchet in the head | (c). SiltHaul's block is limited to 2.5 kN and weighs about 48 kg; with (b) the walkers step over the rope at every turn. With (c) four people stand still on firm ground and give 5 kN at 114 N each | Not a safety choice |
| 2 | Overload | (a) size everything on what four people can heave; (b) a shear pin between the drive ratchet and the drum | (b), conservative: R10 added. The 6 mm S275 pin releases at about 6.4 kN; every part, the rope, the slings and the anchor are sized on 8 kN | Release tests on a batch of pins with a tighter spread could raise the working pull, never the design tension |
| 3 | Holding | (a) the tailer holds the load; (b) two pawls on a ratchet ring at the drum's foot, and the tail made fast on a cleat whenever hauling stops | (b), conservative: R11 added | None proposed |
| 4 | Capstan anchor | (a) ground stakes or a picket holdfast; (b) a round sling to a sound tree, a parked vehicle's recovery point or a structural column, with stakes only against turning | (b), conservative. Never waste, never stakes alone. Where there is no sound anchor the capstan is not used | Pull tests of a picket holdfast in the local natural ground to twice the 8 kN design tension would allow it as an anchor |
| 5 | Rope | 12 mm or 14 mm polyester double braid | 14 mm, at least 40 kN: factor 4.5 at the design tension through the splice | Not relaxed |
| 6 | What the capstan may pull | (a) anything, including lifting; (b) only sheeting, timber and debris, sideways away from the dig, never lifting and never on a person | (b), conservative. Nobody stands in the line of the rope or within 2 m of it while it is loaded | None proposed; lifting or hauling people needs a different, certified system |
| 7 | Probes | (a) avalanche probes; (b) sectional steel probes pushed by hand; (c) probes driven with a hammer | (b): three 1 m sections of 16 x 2.0 tube with a 22 mm tip rounded to 3 mm. (c) rejected, conservative: a driven probe could injure a buried person | None proposed |
| 8 | Crawl boards | (a) bare plywood sheets; (b) plywood decks on two timber battens, linked end to end | (b): 1500 x 450 mm, 9.7 kg, link plates with pins | Not a safety choice |
| 9 | Stretcher | (a) a bought roll-up rescue stretcher; (b) a made HDPE sheet stretcher with straps | (b): about a fifth of the bought price; the same principle | Not a safety choice |
| 10 | Lighting cells | (a) rechargeable lithium lamps; (b) AA alkaline lamps with the cells stored out | (b), conservative: no lithium cells in a hot shed | Shed temperature records below 45 degrees C and a partner who charges and checks lamps monthly would allow lithium-iron-phosphate lamps |
| 11 | Gas detector | (a) a four-gas detector in the box; (b) no detector; no flames or smoking; stop on any gas smell, smoke or hissing | (b), conservative: an unmaintained detector gives false comfort | A partner who bump-tests and calibrates a detector monthly would allow one to be added |
| 12 | Stop rule | Signals that send everyone to the safe zone | Six signals: the lookout's long whistle; new cracks, bulging or movement above; water or mud flowing from the debris; rain getting heavier; gas smell, smoke or hissing; a formal responder's order. A lookout is posted before anyone steps onto the debris; the safe zone is to the side of the slide path, never below it | None proposed |
| 13 | Co-design partner | Cooperative, municipal unit, NGO or Red Cross branch | First candidate to approach: the Uganda Red Cross Society in Kampala with the waste pickers who work at Kiteezi (not agreed) | |
| 14 | Shared blocks | SiltHaul hand capstan; CalRig proof-load rig | SiltHaul's capstan is not used (item 1). CalRig is the first candidate rig for capstan proof loads and shear pin release tests | |
| 15 | Site box access | (a) key held by one person; (b) combination padlock known to every trained member | (b): no waiting for a key holder (R1). The owner keeps a monthly inspection log | |
| 16 | Budget | Keep `budget_usd` at 1,800 | Kept; it is a value-engineering target, not a limit | |

## Consequences

- R10 (overload limit) and R11 (holds when let go) are added to HPL-REQ-001.
- The design for construction (HPL-DDR-002) works from these choices.
- R2, R5, R8 and R9 are not met or at risk on paper. They are not decided here: each is posed to Amish with options and a recommendation in `docs/REVIEW.md` and listed as open in `docs/06-design-decisions.md`.

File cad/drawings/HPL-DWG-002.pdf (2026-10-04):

CONCEPT, NOT FOR FABRICATION | HeapLine · github.com/BoujeeEnjinia1701/heapline

FRONT VIEW
Scale 1:25; looking at the front (along +Y)

TOP VIEW
Scale 1:25; looking down (along -Z)

RIGHT VIEW
Scale 1:25; looking at the right side (along -X)

3040

906 1108

ISOMETRIC VIEW, LIDS CLOSED
Not to scale; search crate left, capstan crate right; seen from the front right and above, about 30 deg elevation

PACKING AND CRATES (MM)
Search crate, every site: outside 1640 x 860 x 640 on skids (1, 2)
Inside at least 1604 x 824 x 622; corner battens 45
Back: four crawl boards flat; shovels, probe bag on top (4 to 8) Front: lookout and lights bag, PPE bag, stretcher roll on top Capstan crate, host site only: outside 940 x 900 x 1060 (31) Inside at least 904 x 864 x 1042
Capstan upright at the back, bars off, stakes out (9 to 17) Front: rope, slings and clamp, stakes, two bars standing Lids: drill card inside, stop rule outside (27)
Combination padlock on each front hasp (3) Third-angle; front view from -Y; (n) = BOM line
REV | DESCRIPTION | DATE | BY
P1 | Preliminary GA for TRL 3 (from cad/src/model.py) | 2026-10-03 | AC
P2 | HPL-DDR-002: design for construction | 2026-10-03 | AC
P3 | HPL-DDR-003: search crate at every site, capstan crate at the host site | 2026-10-03 | AC
HEAPLINE | github.com/BoujeeEnjinia1701/heapline

## Search crate and capstan crate: packed arrangement

DRAWING NO.
HPL-DWG-002

REV
P3

SHEET
1 of 1

SIZE

## ANSI B

SCALE
1:25

UNITS
mm
PROJECTION | DATE
2026-10-03

DRAWN
Amish Chadha

MATERIAL / NOTES
Reused timber crates (or bought job boxes) of at least these sizes; contents per bom/bom.csv. PRELIMINARY, NOT FOR FABRICATION
Licensed CERN-OHL-S-2.0 · Design Molecule Lab · designmolecule.com | Generated from cad/src; do not edit by hand

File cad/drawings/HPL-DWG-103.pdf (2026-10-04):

### BUILD PLAN SKETCH, PLAN NOT YET BUILT HeapLine · github.com/BoujeeEnjinia1701/heapline

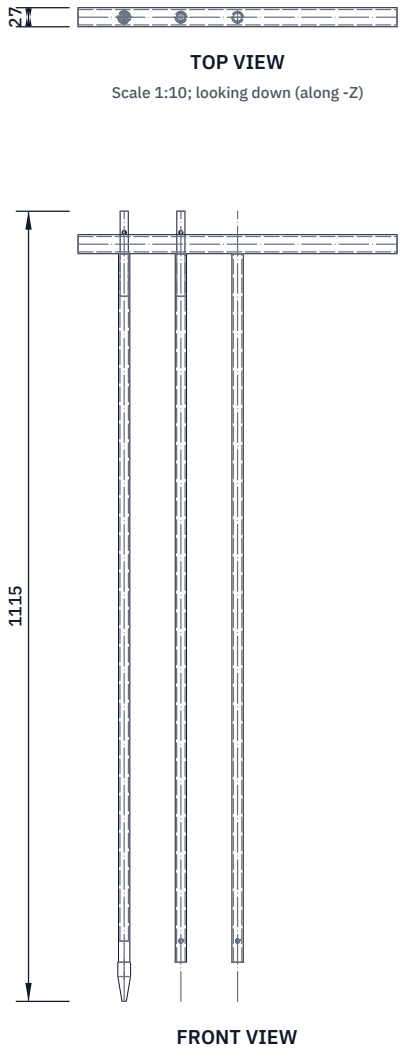
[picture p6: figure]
FRONT VIEW; TOP VIEW; Scale 1:10; looking down (along -Z)

Scale 1:10; looking at the front (along +Y)

RIGHT VIEW
Scale 1:10; looking at the right side (along -X)

450

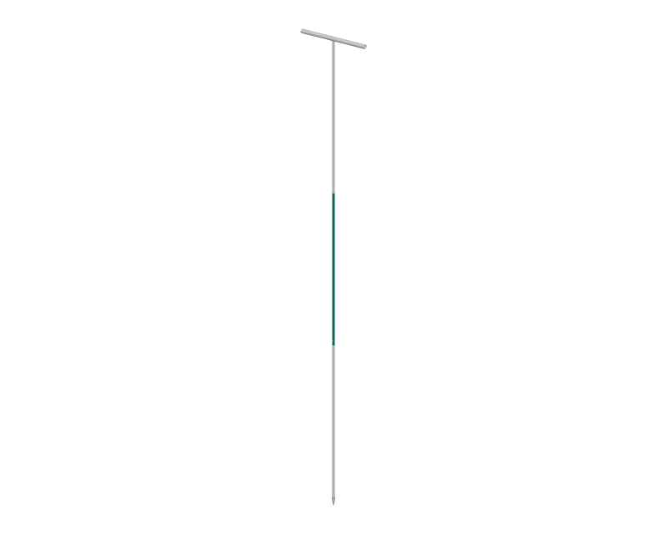
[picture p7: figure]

WHERE IT GOES
This part in colour, its neighbours in grey

HOW TO MAKE IT AND HOW IT FITS
Three sections of 16 x 2.0 tube, each 1000 long, ends square
Spigot 11.5 dia x 120 into the top of the tip and middle sections, 60 in; plug weld Tip from 18 bar: cone 35 long to a 3 mm rounded point, 20 parallel, 30 x 12 spigot T handle 26.9 x 2.6 x 450 welded square across the top section
5 mm cross hole 30 above each joint, through tube and spigot together
Paint a band every 250 from the tip; R-clip on a lanyard at each joint
Make 6 sets. Check: assembled 3068 long, straight within 10 mm
REV | DESCRIPTION | DATE | BY
P1 | Making sketch for the prototype build plan | 2026-10-03 | AC
HEAPLINE | github.com/BoujeeEnjinia1701/heapline

## Probe sections: making sketch

DRAWING NO.
HPL-DWG-103

REV
P1

SHEET
1 of 1

SIZE

## ANSI B

SCALE
1:10

UNITS
mm
PROJECTION | DATE
2026-10-03

DRAWN
Amish Chadha

MATERIAL / NOTES
16 x 2.0 steel tube; 11.5 and 18 mm bright bar; 26.9 x 2.6 tube
Licensed CERN-OHL-S-2.0 · Design Molecule Lab · designmolecule.com | Generated from cad/src; do not edit by hand

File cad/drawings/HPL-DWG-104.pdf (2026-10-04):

### BUILD PLAN SKETCH, PLAN NOT YET BUILT HeapLine · github.com/BoujeeEnjinia1701/heapline

FRONT VIEW
Scale 1:20; looking at the front (along +Y)

TOP VIEW
Scale 1:20; looking down (along -Z)

RIGHT VIEW
Scale 1:20; looking at the right side (along -X)

873

507 995

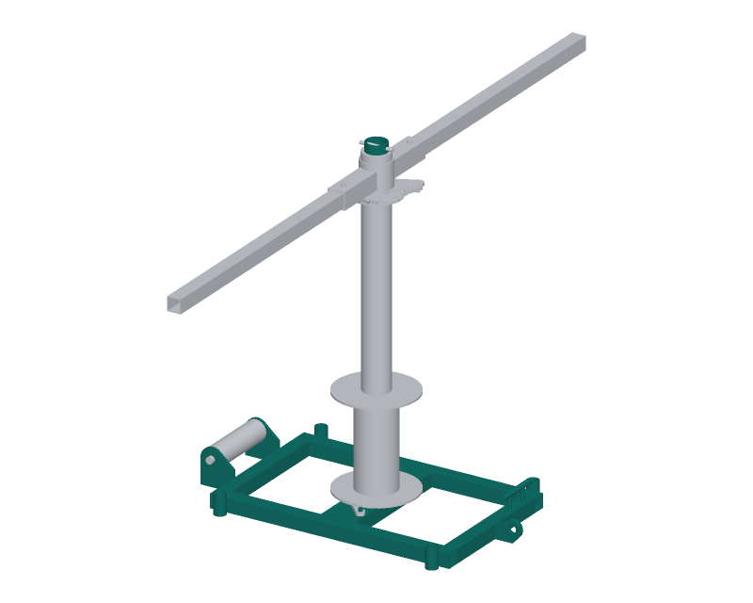
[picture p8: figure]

WHERE IT GOES
This part in colour, its neighbours in grey

HOW TO MAKE IT AND HOW IT FITS
Frame 700 x 440 outside: two rails, two cross members, 40 x 40 x 3
Centre member 100 x 40 x 4 across the middle; 61 mm hole top and bottom Post 60.3 x 5.0 x 995 through the centre member, square, welded top and bottom Roller cheeks 8 mm on the front, 20.5 hole at 75 up, 65 ahead of the frame Anchor eye 10 mm on the rear, 22 hole at 38 up; tail cleat on the rear member Two 12 mm pawl pins on the centre member; four stake tubes at the corners 10.5 mm cross hole through the post at 982 up
Check: post square to the frame within 1 mm over 900
REV | DESCRIPTION | DATE | BY
P1 | Making sketch for the prototype build plan | 2026-10-03 | AC
HEAPLINE | github.com/BoujeeEnjinia1701/heapline

## Capstan base frame with post: making sketch

DRAWING NO.
HPL-DWG-104

REV
P1

SHEET
1 of 1

SIZE

## ANSI B

SCALE
1:20

UNITS
mm
PROJECTION | DATE
2026-10-03

DRAWN
Amish Chadha

MATERIAL / NOTES
40 x 40 x 3 SHS; 100 x 40 x 4 RHS; 60.3 x 5.0 tube; 8, 10 mm plate
Licensed CERN-OHL-S-2.0 · Design Molecule Lab · designmolecule.com | Generated from cad/src; do not edit by hand

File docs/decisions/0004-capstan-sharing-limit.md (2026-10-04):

---
doc_id: HPL-DDR-004
title: HeapLine siting limit for a shared capstan set
project: HeapLine
doc_type: Design decision record
version: "0.1"
status: Draft
date: '2026-10-04'
author: Amish Chadha
license: CERN-OHL-S-2.0
revisions:
- version: "0.1"
  date: '2026-10-04'
  author: Amish Chadha
  change: Amish's round-3 decision 3A recorded
---

# 0004: Siting limit for a shared capstan set

- **Date:** 2026-10-04
- **Status:** accepted. Decided by Amish on 2026-10-04: "For round 3, I agree with all your proposed recommendations". For HeapLine this accepts option (a) of open decision 1 in HPL-DEC-001 (portfolio item 3A).

## Context

Decisions 22A and 23C keep one capstan set at the host site, brought by a second wave of three people. Its arrival grows with the walk from the host shed: 3.8 min after the alarm from 100 m, 9.2 min from 300 m, 14.8 min from 500 m, 28.5 min from 1 km [F4].

## Options considered

(a) Share only between sites within about 500 m walk of the host shed. (b) Share within about 1 km. (c) No limit, agreed site by site. Recommendation was (a).

## Decision

A shared capstan serves only sites within about 500 m walk of the host shed, so it arrives within about 15 min. Farther sites keep their own capstan set (USD 547) or rely on the search kit alone. The limit is checked in the TRL 4 timed drills (capstan wave drill, build plan Table 2).

## Consequences

Requirements text, calculation note, build plan drill table and registers only. No geometry or cost change. Value-engineering target: USD 1,800. Estimated cost of the constructable design: USD 1,374.00 (USD 426.00 under the target).

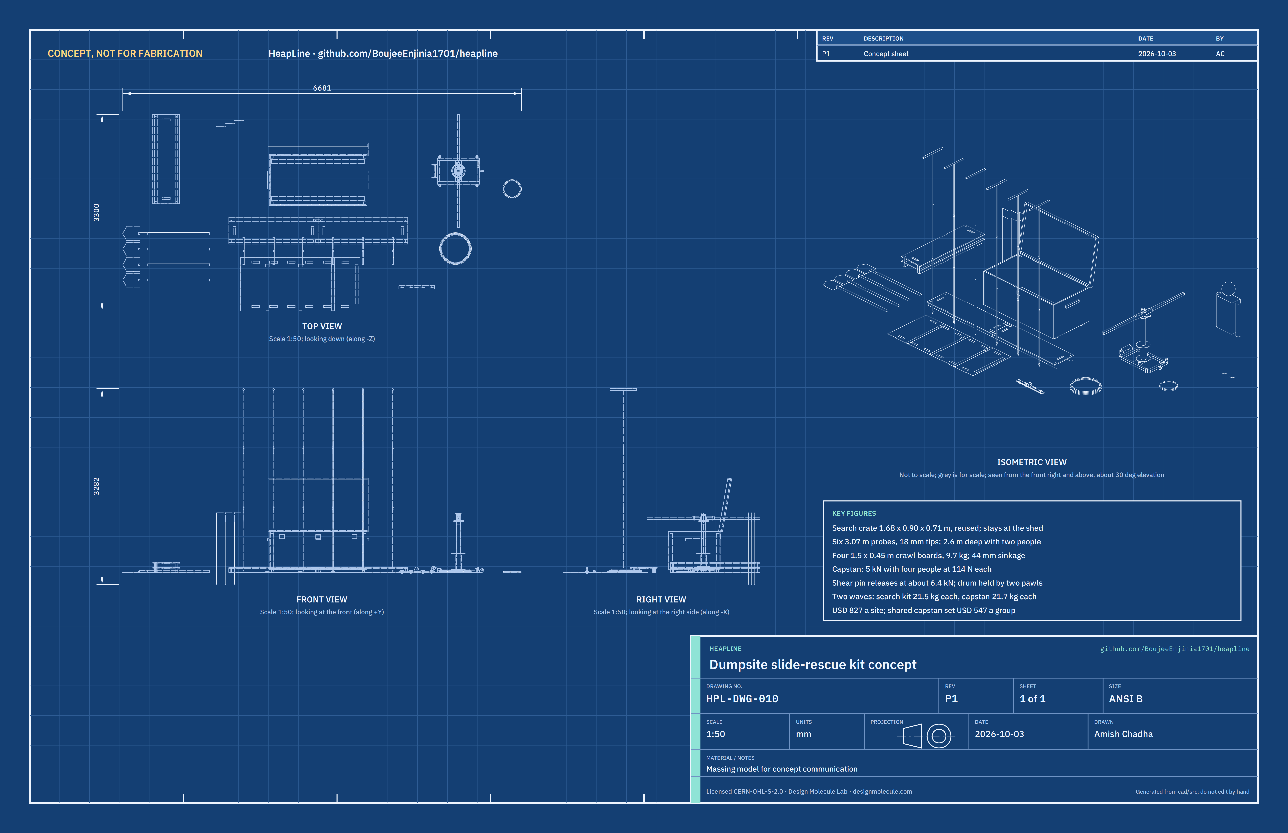
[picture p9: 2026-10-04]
media/concept-blueprint.png

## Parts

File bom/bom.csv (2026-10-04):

item | qty | spec | supplier | unit_cost_usd | make_buy | notes
1 Search crate body | 1 | Reused timber shipping crate or lidded pallet box, sound and dry, refitted: at least 1604 x 824 mm inside and 622 mm deep (outside about 1640 x 860 x 640 mm); two 70 x 45 mm treated timber skids screwed under it; 45 x 45 mm treated timber corner battens where it has none; two hardwood rope-handle cleats; exterior paint. Where no crate can be had, a bought steel job box of at least the same inside size (not in this total) | Importer, timber yard or packaging recycler | 40.00 | buy | Indicative price basis: used crates and pallet boxes about USD 0 to 30 at importers and timber yards, plus about USD 10 to 15 of timber, screws and paint for the refit; about 52 kg as modelled in 18 mm boards (cad/src/model.py); a bought steel job box of this size costs about USD 300 to 600. One per site (decision 23C, HPL-DDR-003); stays at the shed and is never carried to a slide
2 Search crate lid | 1 | The crate's own lid, refitted with a 48 mm skirt of 18 mm board all round that overlaps the body; drill card and stop rule on the lid (line 27) | Comes with the crate (line 1) | 10.00 | make | Indicative price basis: about 4 m of 48 x 18 mm treated batten and screws for the skirt; about 17 kg as modelled; held open by a folding steel stay (line 3)
3 Crate hardware | 1 | Three galvanised strap hinges 300 mm; one heavy hasp and staple; one combination padlock (shrouded, weatherproof); folding steel lid stay; EPDM seal strip 10 x 3 mm, 5.0 m; four rope handles (12 mm rope) | Hardware store | 48.00 | buy | Indicative price; combination padlock so every trained member can open it without a key holder
4 Crawl boards | 4 | Deck 15 mm exterior plywood 1500 x 450 mm with two hand slots 140 x 35 mm; two 45 x 70 mm treated timber battens 1500 mm long, 30 mm in from the edges; four 13 mm link holes; glued and screwed (5 x 60 mm stainless screws); anti-slip grit paint on the deck | Timber merchant | 24.00 | make | Indicative price; 9.7 kg each (cad/src/model.py)
5 Board link plates | 8 | 40 x 6 mm steel flat 160 mm long with two 12 mm round bar pins 75 mm long welded under it, 80 mm apart; galvanised or painted | Local steel stockholder | 3.00 | make | Indicative price; two per joint between boards; four spare
6 Probes | 6 | Three sections of 16 x 2.0 mm steel tube 1000 mm long; 11.5 mm bright bar spigots 120 mm long welded half into the top of the lower two sections; tip turned from 18 mm bright bar (35 mm cone with a 3 mm rounded point, 20 mm parallel, 30 mm spigot) welded into the bottom section; T handle 26.9 x 2.6 mm tube 450 mm long; depth bands painted every 250 mm | Local steel stockholder and machine shop | 24.00 | make | Indicative price, unchanged with the 18 mm tip (decision 20A, HPL-DDR-003; 18 mm bar costs the same or less than 22 mm); 3.07 kg each; 3.07 m assembled
7 Probe joint pins | 16 | R-clip (hitch pin clip) for a 5 mm hole, zinc plated, on a short lanyard | Fastener supplier | 0.50 | buy | Indicative price; two per probe and four spare
8 Shovels | 4 | Long-handled round-point steel shovel, overall about 1.45 m, ash or fibreglass handle | Hardware store | 18.00 | buy | Indicative price; about 2.3 kg each
9 Capstan base frame with post | 1 | Welded frame: 40 x 40 x 3 mm steel square tube about 2.1 m (two rails 700 mm, two cross members); 100 x 40 x 4 mm rectangular tube 360 mm (centre member); 60.3 x 5.0 mm steel tube 995 mm (post) through the centre member and welded above and below; four stake tubes 33.7 x 3.2 x 60 mm; two 8 mm roller cheek plates; 10 mm anchor eye plate with a 22 mm hole; tail cleat from 12 and 16 mm bar; two 12 mm pawl pins; 10 mm cross hole near the post top | Local steel stockholder | 62.00 | make | Indicative price; 19.2 kg (cad/src/model.py)
10 Capstan drum with holding ratchet | 1 | 114.3 x 3.6 mm steel tube 260 mm long (barrel); two 6 mm discs 230 mm OD; 76.1 x 3.2 mm tube 528 mm long (spindle); 8 mm top flange 140 mm OD with a 6.2 mm shear pin hole on a 60 mm radius; 24-tooth holding ratchet ring 210 mm OD from 6 mm plate (laser or plasma cut) | Local steel stockholder and profile cutter | 70.00 | make | Indicative price including profile cutting; 11.1 kg
11 Drive ratchet wheel | 1 | 20-tooth ratchet wheel 160 mm OD from 8 mm plate (laser or plasma cut), 61.3 mm bore, 6.2 mm shear pin hole on a 60 mm radius | Local profile cutter | 12.00 | make | Indicative price
12 Lever head | 1 | 88.9 x 5.0 mm steel tube 80 mm long (sleeve); two 50 x 50 x 3 mm square tube sockets 150 mm long with 13 mm pin holes; 8 mm pawl bracket plate; 12 mm pawl pin | Local steel stockholder | 20.00 | make | Indicative price; 2.4 kg
13 Pawls | 3 | Two holding pawls from 10 mm plate and one drive pawl from 8 mm plate, profile cut, 12.5 mm pivot hole; light torsion springs; washers and R-clips | Local profile cutter | 6.00 | make | Indicative price
14 Capstan bars | 2 | 40 x 40 x 2.5 mm steel square tube 900 mm long with a 13 mm cross hole; 12 mm bar pin with R-clip each; plastic end caps | Local steel stockholder | 10.00 | make | Indicative price; 2.6 kg each
15 Bushes and thrust washers | 1 | Acetal (POM) tube and plate: foot bush 75 x 60.5 x 12 mm; spindle bush 69.7 x 60.5 x 58 mm; head bush 78.9 x 60.5 x 80 mm; three thrust washers 4 and 2 mm thick | Plastics stockholder | 28.00 | make | Indicative price; turned or cut from acetal stock
16 Hold-down roller and pin | 1 | 60.3 x 3.6 mm steel tube 200 mm long with two acetal end bushes; 20 mm bright bar pin 240 mm long with R-clips | Local steel stockholder | 15.00 | make | Indicative price
17 Keeper collar and pin | 1 | Steel collar 80 mm OD x 61 mm bore x 20 mm; 10 mm pin 96 mm long with an R-clip | Local steel stockholder | 6.00 | make | Indicative price
18 Shear pins | 20 | 6 mm round bar, S275 bright mild steel (not hardened), cut 32 mm long, with a split pin each | Local steel stockholder or fastener supplier | 0.30 | buy | Indicative price; releases at about 6.4 kN rope tension (HPL-CAL-001); spares on a tag chain at the capstan
19 Ground stakes and mallet | 1 | Four stakes from 25 mm round steel bar 500 mm long, pointed, with a 44 mm washer welded on as a head; one 1.8 kg club hammer | Local steel stockholder and hardware store | 32.00 | make | Indicative price; stakes stop the frame turning and skating; they are not the anchor
20 Capstan rope | 30 | 14 mm polyester double braid, minimum breaking strength at least 40 kN; one eye splice with a thimble at the load end | Rope or chandlery supplier | 2.40 | buy | Indicative price per metre including the splice; 30 m
21 Slings and shackles | 1 | Two polyester round slings WLL 2,000 kg (3 m and 2 m effective length); three bow shackles WLL 2,000 kg with 19 mm pins; one tree protector strap | Lifting gear supplier | 66.00 | buy | Indicative price; one sling for the anchor and one as a choker on timber or debris
22 Sheet clamp | 1 | Two 50 x 8 mm steel flats 600 mm long with four 13 mm holes; four M12 x 60 bolts with wing nuts and washers; 10 mm lug plate with a 22 mm hole welded to the upper flat | Local steel stockholder | 22.00 | make | Indicative price; 4.6 kg; grips plastic sheeting or tarpaulin for the capstan
23 Sheet stretcher | 1 | 2 mm UV-stabilised HDPE sheet 2000 x 900 mm with twelve hand slots 130 x 35 mm; three 50 mm polyester webbing straps with cam buckles, riveted; a head haul strap; rolls to about 250 mm diameter | Plastics stockholder and webbing supplier | 82.00 | make | Indicative price; 3.9 kg
24 Lookout kit | 1 | Two pealess whistles; six high-visibility vests; twenty 1 m fibreglass marker wands with orange flags; one safe-zone sign 300 x 200 mm on a stake; two armbands for the lookout and the search leader | Safety supplier | 75.00 | buy | Indicative price
25 Lighting | 1 | Six head lamps and two hand lamps taking AA alkaline cells (no lithium cells in the box); 24 AA alkaline cells stored in their packet, out of the lamps | Hardware or outdoor store | 95.00 | buy | Indicative price; cells checked at each inspection
26 Personal protective equipment | 1 | From the cooperative's own stock (decision 23C, HPL-DDR-003), kept in the PPE bag in the search crate: eight pairs of cut-resistant gloves (EN 388 level C or better); four pairs of rubber safety boots with a steel midsole in mixed sizes; ten FFP2 masks; six pairs of safety glasses | Cooperative's own stock | 0.00 | buy | No cost to the kit; about USD 168 if it has to be bought from a safety supplier. Checked at each monthly inspection; anything missing is replaced by the cooperative
27 Drill card and stop rule | 1 | Weatherproof printed drill card and stop rule on the lid (inside and out); ten laminated A5 pocket cards; inspection log sheet | Print shop | 25.00 | buy | Indicative price; wording in HPL-PRC-001
28 Carry bags | 1 | Probe bag 160 mm diameter x 1.2 m; rope bag; slings and clamp bag; lookout and lights bag; PPE bag; two carry straps for the capstan frame and drum | Outdoor or bag supplier | 48.00 | buy | Indicative price
29 Fasteners | 1 | Stainless screws for the boards and box; M12 bolts for the clamp; spare R-clips and split pins | Fastener supplier | 25.00 | buy | Indicative price
30 Paint and consumables | 1 | Zinc-rich primer and paint for steel; exterior paint for plywood; anti-slip grit; welding wire or electrodes; grinding and cutting discs | Hardware store | 35.00 | buy | Indicative price
31 Capstan crate | 1 | Host site only, for the shared capstan set (decision 23C, HPL-DDR-003): a second reused timber crate, at least 904 x 864 mm inside and 1042 mm deep (outside about 940 x 900 x 1060 mm), refitted like lines 1 and 2 with skids, corner battens, a skirted lid, three strap hinges, hasp, combination padlock, lid stay, seal and rope handles; drill card on the lid | Importer, timber yard or packaging recycler; hardware store | 98.00 | buy | Indicative price basis: crate and refit about USD 50 as lines 1 and 2, hardware about USD 48 as line 3; about 64 kg as modelled; one per group of neighbouring sites, part of the shared capstan set

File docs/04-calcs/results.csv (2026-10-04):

id | requirement | result | status
R1 | Deploy fast | 4.6 min estimated from alarm to first probe line | Met on paper; timed drills at TRL 4
R2 | Probe depth | 18 mm tip. Central debris: one person 2.6 m, two 2.6 m; stiff debris: one 0.6 m, two 2.6 m | Met on paper with two people in stiffer debris; confirm on a test heap at TRL 4
R3 | Crawl board support | Sinkage 44 mm; bridges a 0.8 m void at 4.0 MPa | Met on paper
R4 | Capstan pull | Pin releases at 6374 N (5099 to 7648 N); 114 N each for four people at 5,000 N | Met on paper
R5 | Casualty transport | Debris level 510 N: 127 N each for four, 255 N each for two; boards 153 N each for two | Met with the drill-card rule: four haulers on debris, two only along the boards
R6 | Stop rule understood | Stop rule printed on the lid and pocket cards | Not verifiable at TRL 3
R7 | Storage life | Exterior plywood, painted or galvanised steel, UV-stabilised HDPE, alkaline cells stored out | Met on paper by material choice; inspection at TRL 4
R8 | Portable | Heaviest item 21.2 kg; carried kit 151 kg in two waves: search wave 21.5 kg each for four, capstan wave 21.7 kg each for three | Met in two waves
R9 | Cost | USD 827.00 per site search kit against USD 850; shared capstan set USD 547.00 per group of neighbouring sites | Met as restated
R10 | Overload limit | Pin releases at 6374 N nominal, 7648 N at most; rope factor 4.5 at the design tension | Met on paper
R11 | Holds when let go | Two holding pawls; one takes 5.5 kN at 77 MPa tooth bearing | Met on paper

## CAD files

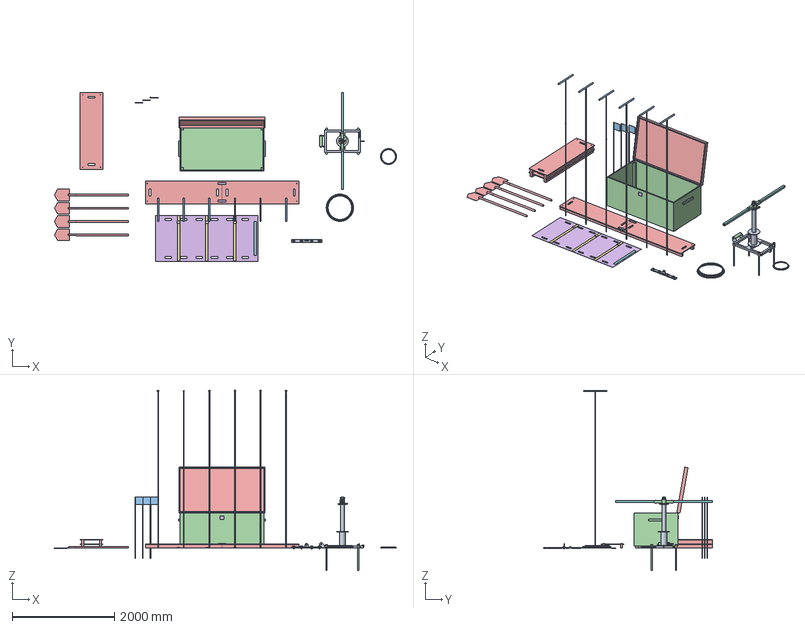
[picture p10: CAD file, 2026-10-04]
cad/step/heapline-assembly.step
6681.0 x 3300.0 x 3521.9 mm

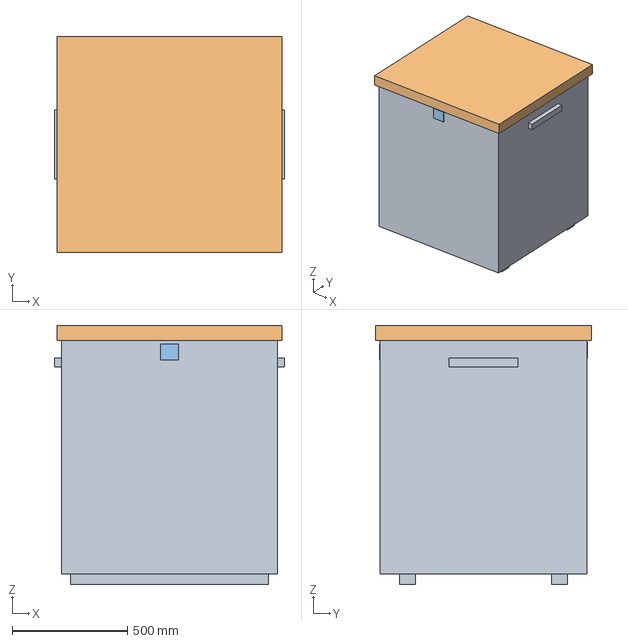
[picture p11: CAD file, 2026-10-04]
cad/step/heapline-capbox.step
1000.0 x 940.0 x 1126.0 mm

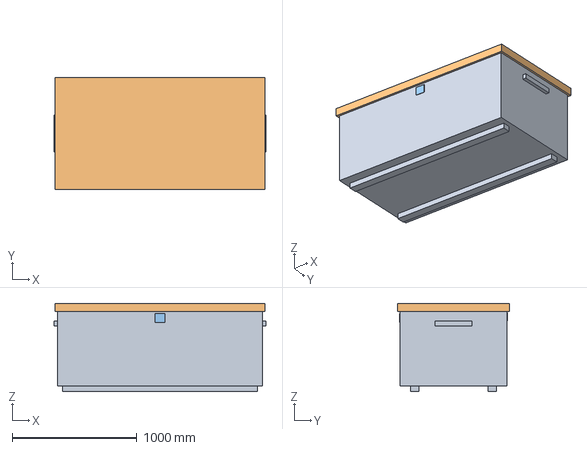
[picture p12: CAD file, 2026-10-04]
cad/step/heapline-box.step
1700.0 x 900.0 x 706.0 mm

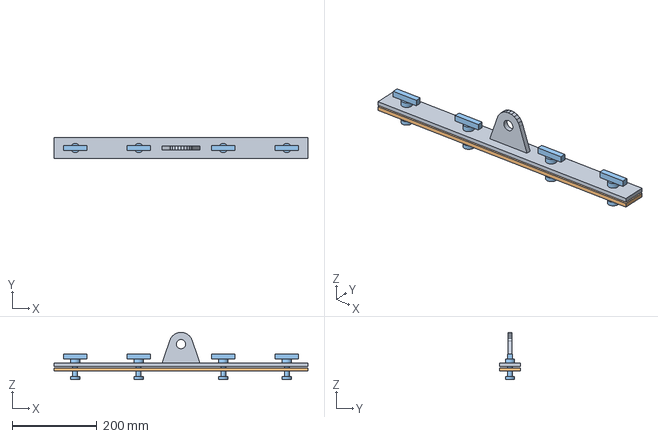
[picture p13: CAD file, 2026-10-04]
cad/step/heapline-clamp.step
600.0 x 50.0 x 112.0 mm

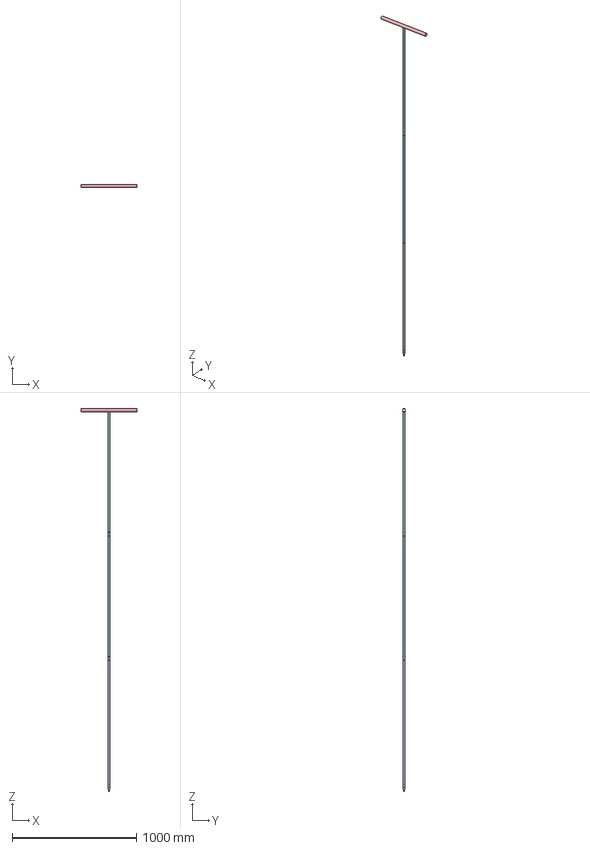
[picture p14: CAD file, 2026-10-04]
cad/step/heapline-probe.step
450.0 x 26.9 x 3081.9 mm

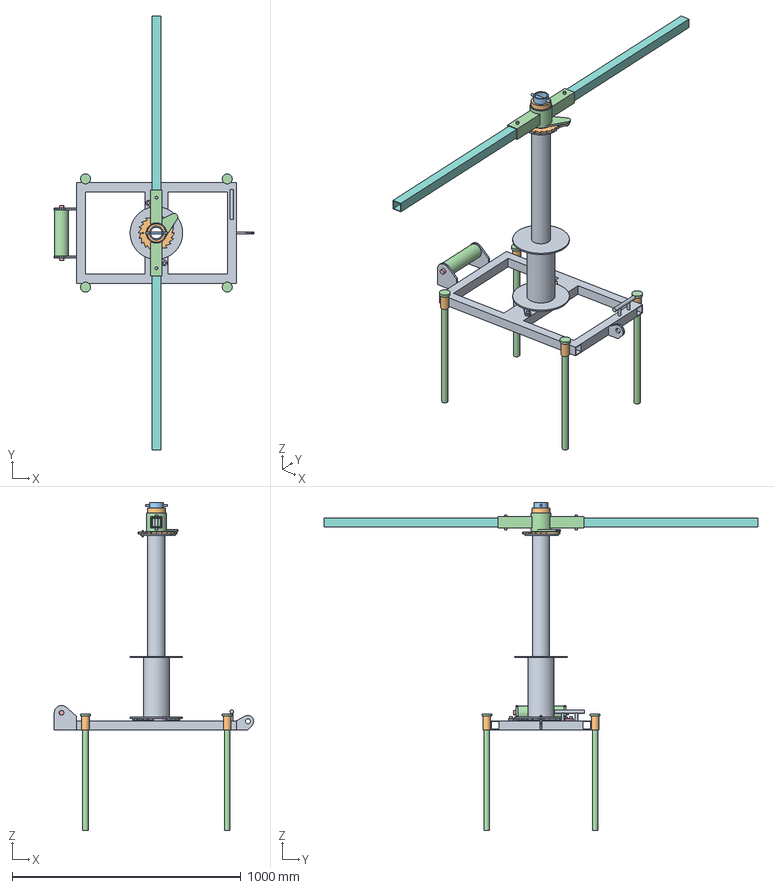
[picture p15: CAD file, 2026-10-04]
cad/step/heapline-capstan.step
873.0 x 1896.9 x 1435.0 mm

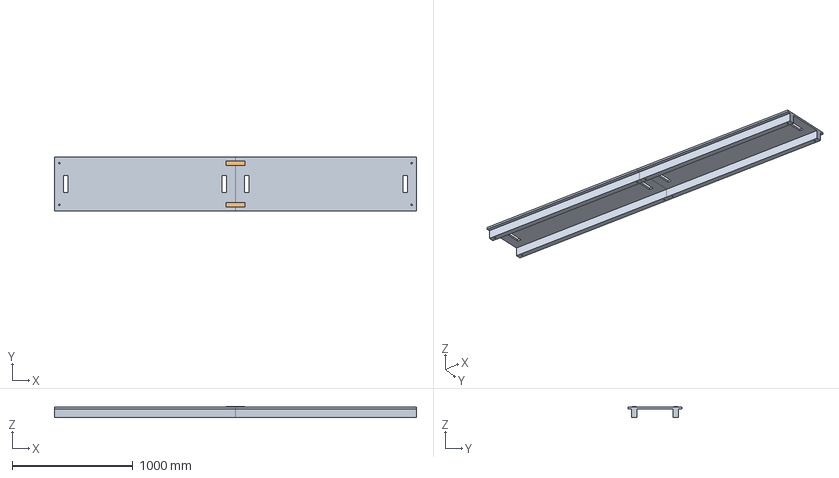
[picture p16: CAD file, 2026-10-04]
cad/step/heapline-board.step
3000.0 x 450.0 x 91.0 mm

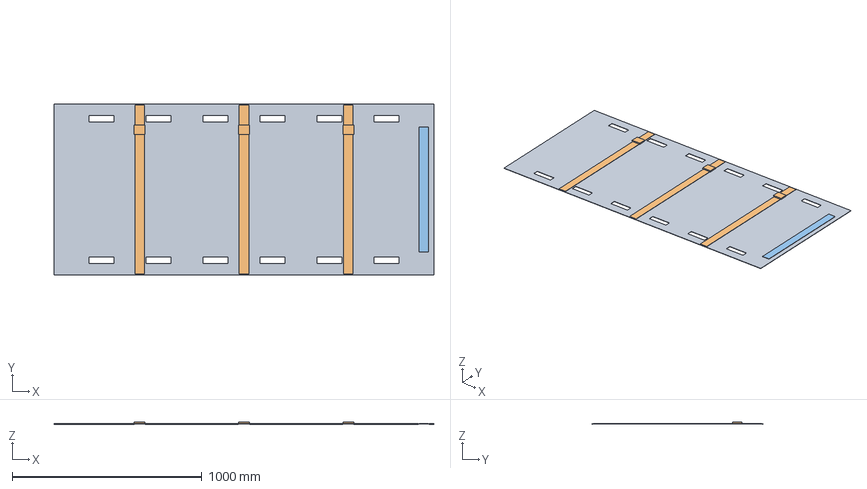
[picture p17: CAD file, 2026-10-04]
cad/step/heapline-stretcher.step
2000.0 x 900.0 x 12.0 mm

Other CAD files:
cad/stl/heapline-board.stl
cad/stl/heapline-box.stl
cad/stl/heapline-capbox.stl
cad/stl/heapline-capstan.stl
cad/stl/heapline-clamp.stl
cad/stl/heapline-probe.stl
cad/stl/heapline-stretcher.stl

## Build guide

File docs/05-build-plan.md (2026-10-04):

---
doc_id: HPL-BLD-001
title: HeapLine prototype build plan
project: HeapLine
doc_type: Build plan
version: "0.3"
status: Draft
date: '2026-10-04'
author: Amish Chadha
license: CERN-OHL-S-2.0
revisions:
- version: "0.1"
  date: '2026-10-03'
  author: Amish Chadha
  change: First build plan; design made constructable (HPL-DDR-002)
- version: "0.2"
  date: '2026-10-03'
  author: Amish Chadha
  change: "Amish's requirement decisions 20A, 21A, 22A and 23C (HPL-DDR-003): 18 mm probe tips; reused search crate at every site and a capstan crate at the host site; PPE from the cooperative; drill-card rules for haulers and the two carrying waves"
- version: "0.3"
  date: '2026-10-04'
  author: Amish Chadha
  change: "Siting limit for the shared capstan set (decision 3A, HPL-DDR-004): about 500 m walk from the host shed, checked in the timed drills; wording only"
---

# HeapLine prototype build plan

**Plan, not yet built.** How to build the first proof-of-concept HeapLine kit, component by component. Building and testing to it is TRL 4 work. Decisions still to be made are kept in the design decisions register (`docs/06-design-decisions.md`), not here.

> **Safety:** HeapLine is a rescue kit for unstable ground and its capstan stores energy in a loaded rope. It is published as an open engineering reference, not certified rescue equipment. The safety stops in section 6 apply to every load test and every drill; no drill is ever run on a real slide or on a slope that could move.

## 1. What you are building

Figure 1. Every component, pulled apart and numbered in build order

*Figure 1. Every component in build order: made parts first, then bought parts.*

One search kit for every site, kept in a reused crate refitted on skids, and one capstan set shared by neighbouring sites, kept in its own crate at the host site. Together they are four crawl boards with eight link plates, six three-section probes, a hand capstan (base frame with a fixed post, drum, drive ratchet, lever head, pawls, bars, bushes, hold-down roller, keeper and stakes), a sheet clamp and a sheet stretcher, plus bought shovels, rope, slings and shackles, lookout kit, lamps and protective equipment, which comes from the cooperative's own stock. Seventeen components are made or refitted: the steel parts by cutting, drilling and welding (MIG or stick), the pawls and ratchets by laser or plasma profile cutting, the bushes by turning acetal, the boards by cutting, gluing and screwing exterior plywood, the crates by refitting reused timber crates, and the stretcher by cutting HDPE sheet and riveting webbing. From the bill of materials, the search kit with its crate costs about USD 827 a site and the shared capstan set with its crate about USD 547; the host site, which keeps both, costs about USD 1,374. A shared capstan serves only sites within about 500 m walk of the host shed; farther sites keep their own capstan set or rely on the search kit alone.

## 2. What changed to make it buildable

*Table 1. Changes from the concept (HPL-DDR-002).*

| Component | The concept had | The buildable design has | Why |
| --- | --- | --- | --- |
| Capstan base | A capstan on a ground anchor, no base | A 700 x 440 mm tube frame with a centre member, stake tubes, roller cheeks, an anchor eye and a tail cleat | Something to carry the post and take the anchor and stakes |
| Post | Not defined | A 60.3 mm tube passing through the centre member, welded at its top and bottom faces (Figure 9) | The two welds carry the bending from the rope |
| Rope lead | Rope leaving the drum about 130 mm up | A hold-down roller takes it down to 38 mm, level with the anchor eye (Figure 20) | The capstan cannot tip; the rope lies along the ground |
| Drum and head | Bars fixed to a drum, walked round | Drum and lever head turn on acetal bushes on the fixed post; the head drives the drum through a ratchet, pumped through a quarter turn | Nobody walks round or steps over a rope |
| Shear pin | Not placed | 6 mm pin joining the drive ratchet to the drum's top flange (Figure 12) | The only path for the drive; it limits the rope tension |
| Pawls | Not drawn | Noses just past a tooth face, pivots along the tangent (Figure 11) | They clear the teeth they ride over |
| Keeper | None | Collar and cross pin on the post top | Nothing slides off when carried |
| Probes | Sectional, joint not defined | Spigot joints with R-clips; tube ends bear; blunt 18 mm tip (Figures 6 and 7) | The push goes through the tube; the tip cannot cut |
| Crawl boards | Loose boards | Boards on two battens joined by pinned link plates (Figure 3) | Boards stay in line on the debris |
| Crates | A box for the kit | A reused search crate at every site, at least 1604 x 824 x 622 mm inside, and a capstan crate at the host site, at least 904 x 864 x 1042 mm inside, capstan upright (Step 11) | The concept box could not hold the capstan or the boards; one capstan is shared by neighbouring sites (HPL-DDR-003) |
| Sheet clamp | None | A bolted two-bar clamp with a shackle lug (Figure 24) | Something to grip plastic sheeting |

## 3. Making the components

Sizes are in millimetres. Weld with MIG, or with 2.5 mm stick electrodes on the 2 and 3 mm walls. Prime and paint every steel part after making it, except the bores and the pin holes.

### 3.1 Crawl boards (make 4)

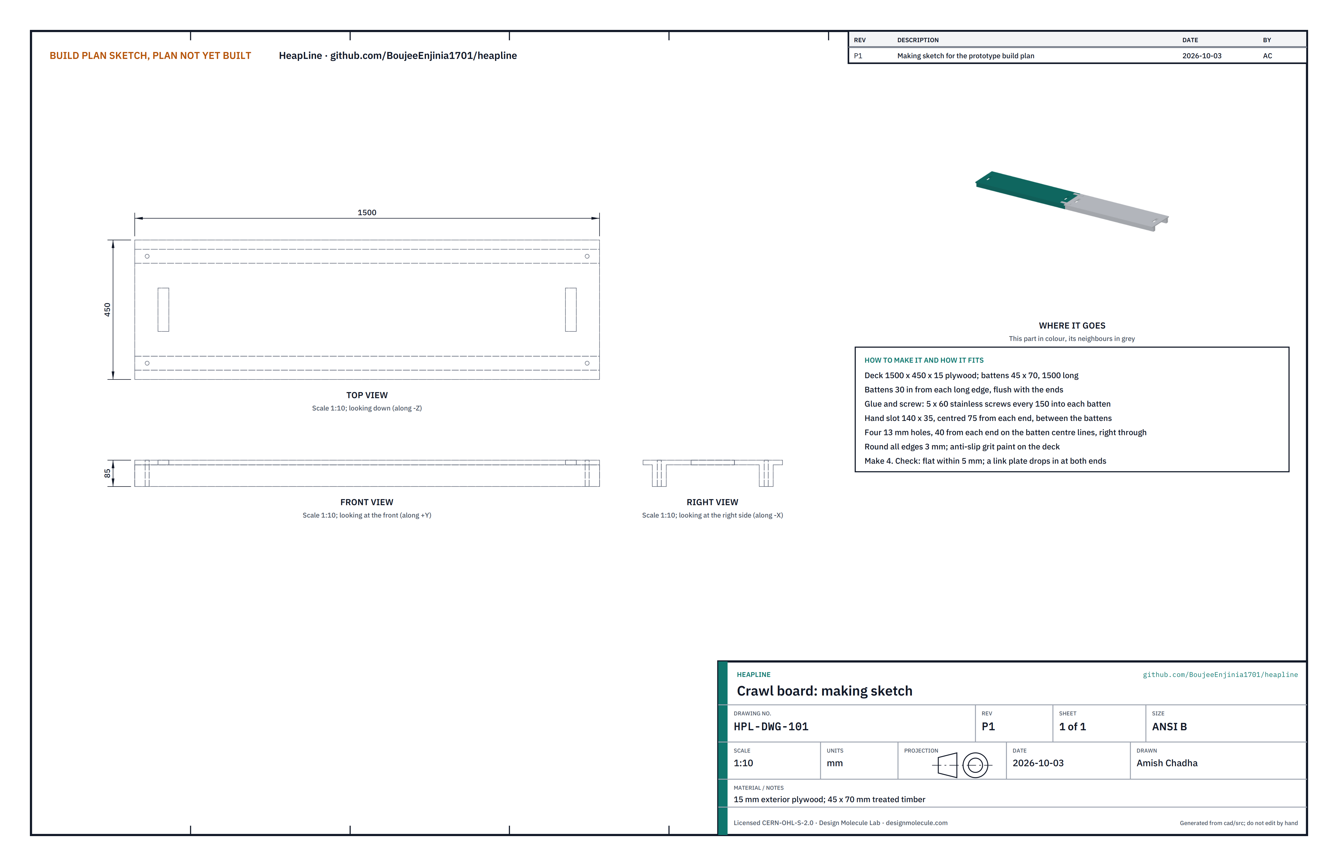
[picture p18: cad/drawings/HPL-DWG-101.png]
Figure 2. Making sketch of a crawl board


*Figure 2. Crawl board making sketch (HPL-DWG-101).*

**What it is and what it is made from.** The board searchers kneel and walk on. 15 mm exterior plywood 1500 x 450; two 45 x 70 treated softwood battens 1500 long; 5 x 60 stainless screws; exterior glue; anti-slip grit paint.

**How to make it.**

1. Cut the deck 1500 x 450 and round all its edges to about 3 mm.
2. Cut a hand slot 140 x 35 centred on the deck's width, its near edge 75 from each end.
3. Glue and screw the battens under the deck on their 70 mm edge, 30 in from each long edge and flush with both ends, screws every 150.
4. Drill four 13 mm holes right through deck and batten, 40 from each end on the batten centre lines.
5. Paint the deck with anti-slip grit paint and seal every cut edge.

**How it fits the parts next to it.**

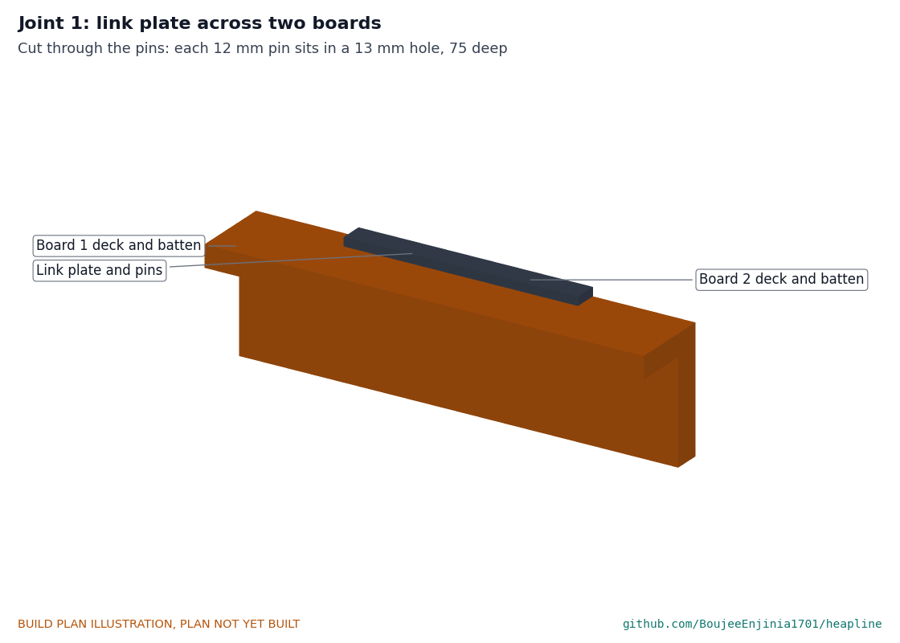
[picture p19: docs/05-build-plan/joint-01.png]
Figure 3. Joint 1: link plate across two boards


*Figure 3. Joint 1, cut through the pins. Two boards butt end to end; a link plate lies on the decks over each batten line and its two 12 mm pins drop into the 13 mm holes, 75 deep.*

**Check before moving on.** The board lies flat within 5 mm; a link plate drops into the holes at either end.

### 3.2 Board link plates (make 8)

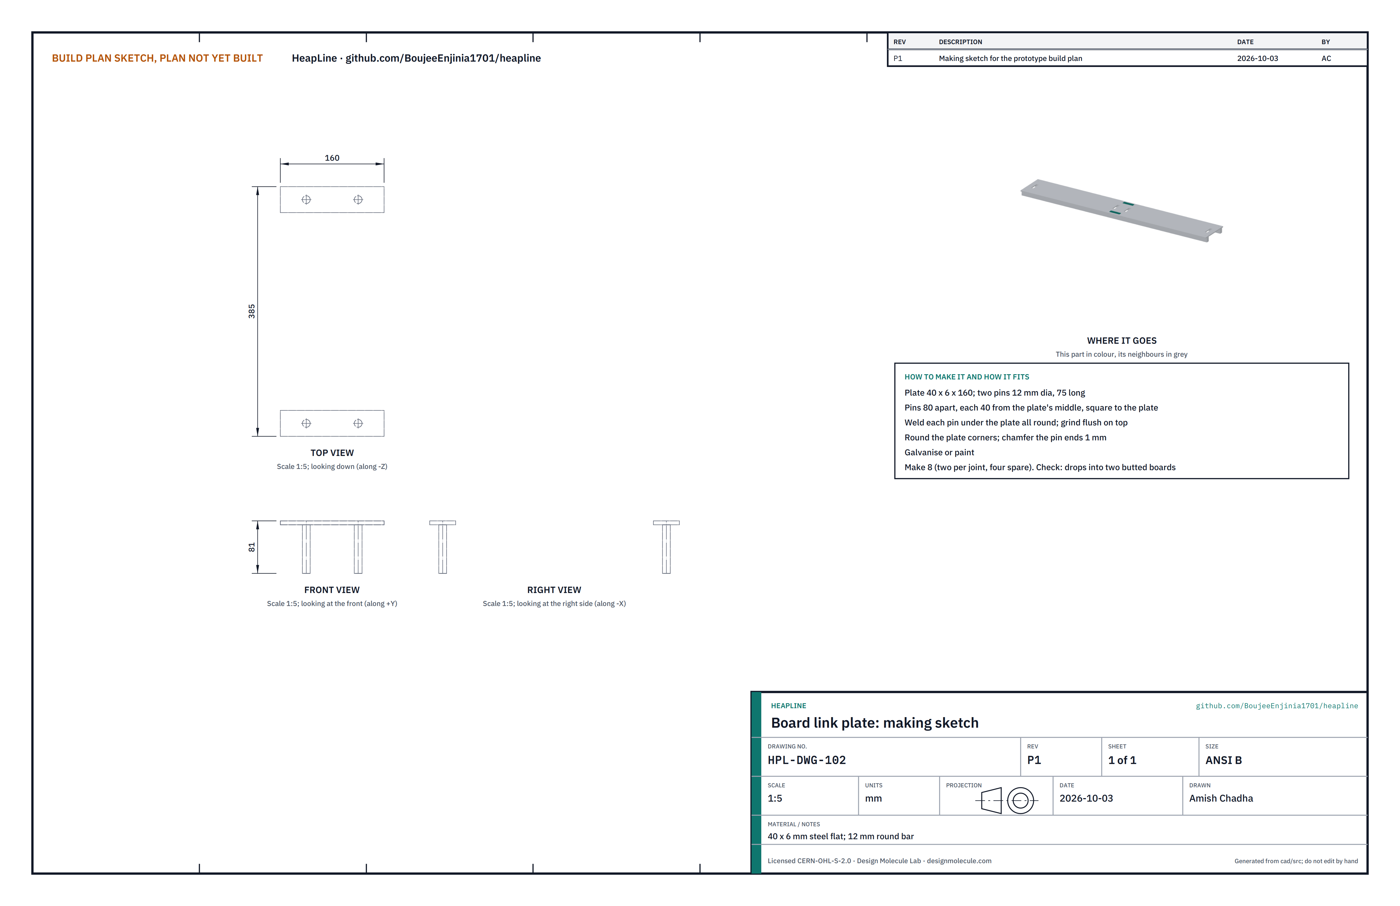
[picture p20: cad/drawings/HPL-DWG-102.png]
Figure 4. Making sketch of a link plate


*Figure 4. Link plate making sketch (HPL-DWG-102).*

**What it is and what it is made from.** The plate that holds two boards in line. 40 x 6 steel flat 160 long; 12 mm round bar.

**How to make it.**

1. Cut the plate and round its corners.
2. Cut two pins 75 long and chamfer their ends.
3. Weld the pins square under the plate, 80 apart (40 each side of the middle), and grind the welds flush on top.
4. Galvanise or paint.

**How it fits the parts next to it.** See Figure 3: one plate on each batten line of a joint.

**Check before moving on.** Each plate drops into two butted boards without forcing.

### 3.3 Probes (make 6 sets of three sections)

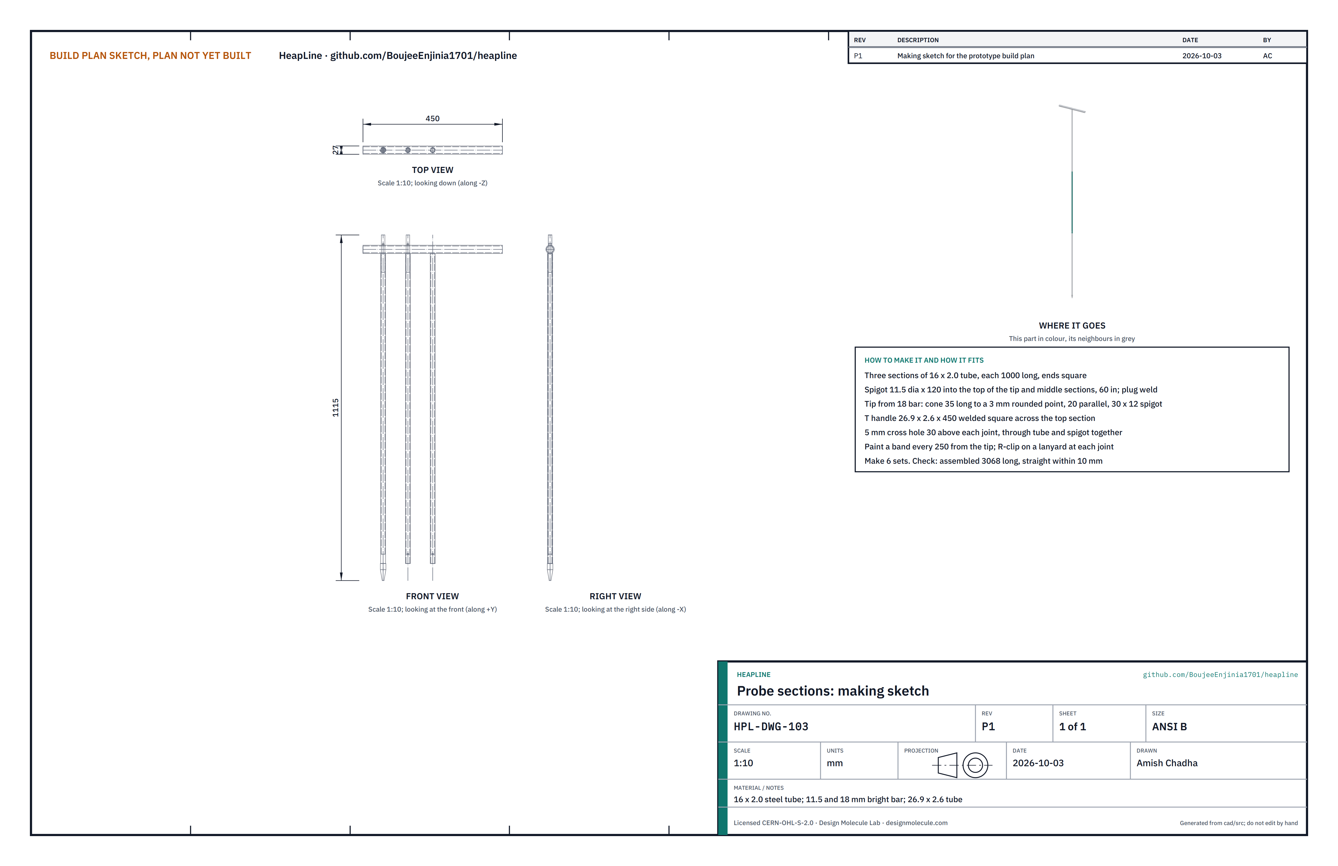
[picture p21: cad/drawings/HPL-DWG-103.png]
Figure 5. Making sketch of the probe sections


*Figure 5. Probe sections making sketch (HPL-DWG-103), sections drawn side by side.*

**What it is and what it is made from.** A 3.07 m probe in three sections that join on spigots. 16 x 2.0 steel tube; 11.5 mm and 18 mm bright bar; 26.9 x 2.6 tube for the handle; R-clips on lanyards.

**How to make it.**

1. Cut three tubes 1000 long, ends square and deburred.
2. Turn the tip from 18 mm bar: a 35 long cone ending in a 3 mm rounded point, 20 parallel, and a 12 mm spigot 30 long. Push the spigot into one tube and plug weld it. This is the tip section.
3. Cut two spigots of 11.5 mm bar 120 long. Push one 60 into the top of the tip section and one into the top of the middle section; plug weld.
4. Weld the 450 handle tube square across the top of the third tube.
5. Fit each upper section over its spigot, ends tight, and drill a 5 mm hole through tube and spigot together, 30 above the joint.
6. Paint a band every 250 from the tip, so the depth can be read.

**How it fits the parts next to it.**

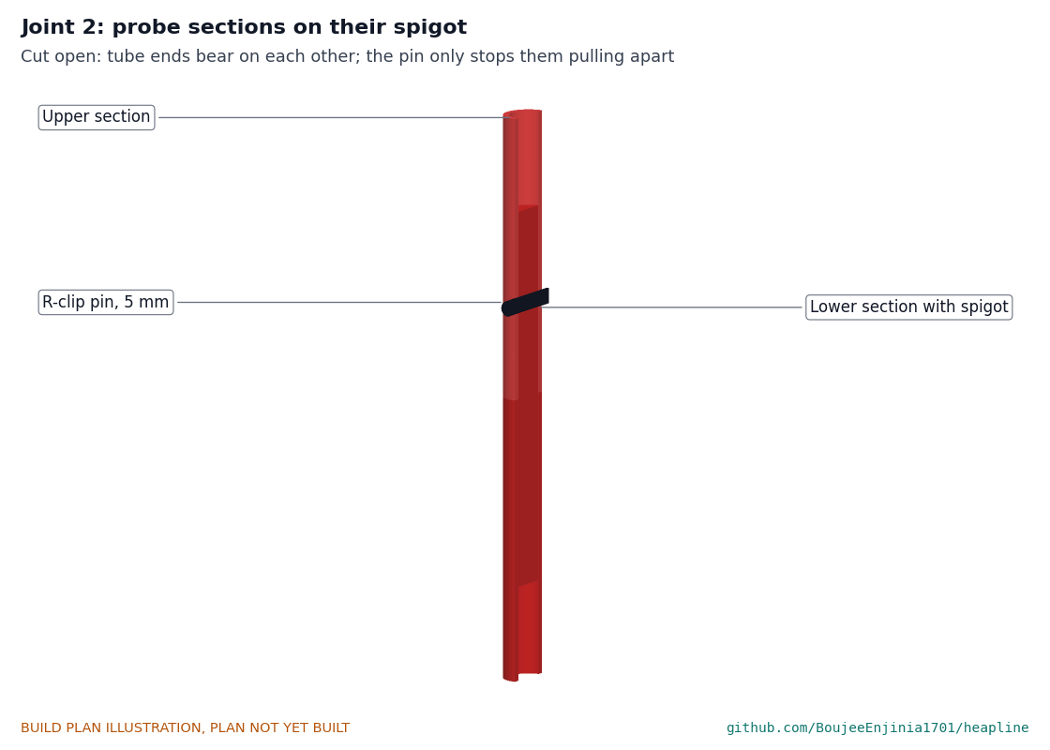
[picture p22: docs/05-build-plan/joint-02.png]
Figure 6. Joint 2: probe sections on their spigot


*Figure 6. Joint 2, cut open. The tube ends bear on each other when the probe is pushed; the R-clip only stops the sections pulling apart.*

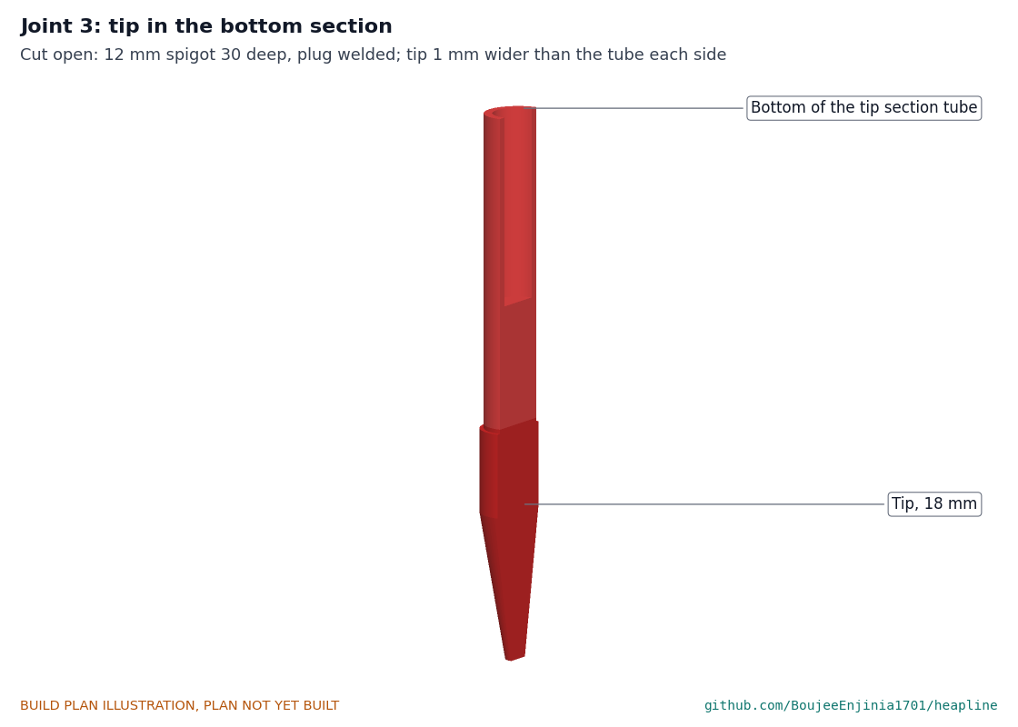
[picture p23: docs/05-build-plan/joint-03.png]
Figure 7. Joint 3: tip in the bottom section


*Figure 7. Joint 3, cut open. The 18 mm tip is 1 mm wider than the tube each side: small enough to start in stiff debris, still clearing a path for the tube behind it.*

**Check before moving on.** Each probe is 3068 long assembled and straight within 10 mm; the sections of any probe fit any other.

### 3.4 Capstan base frame with post

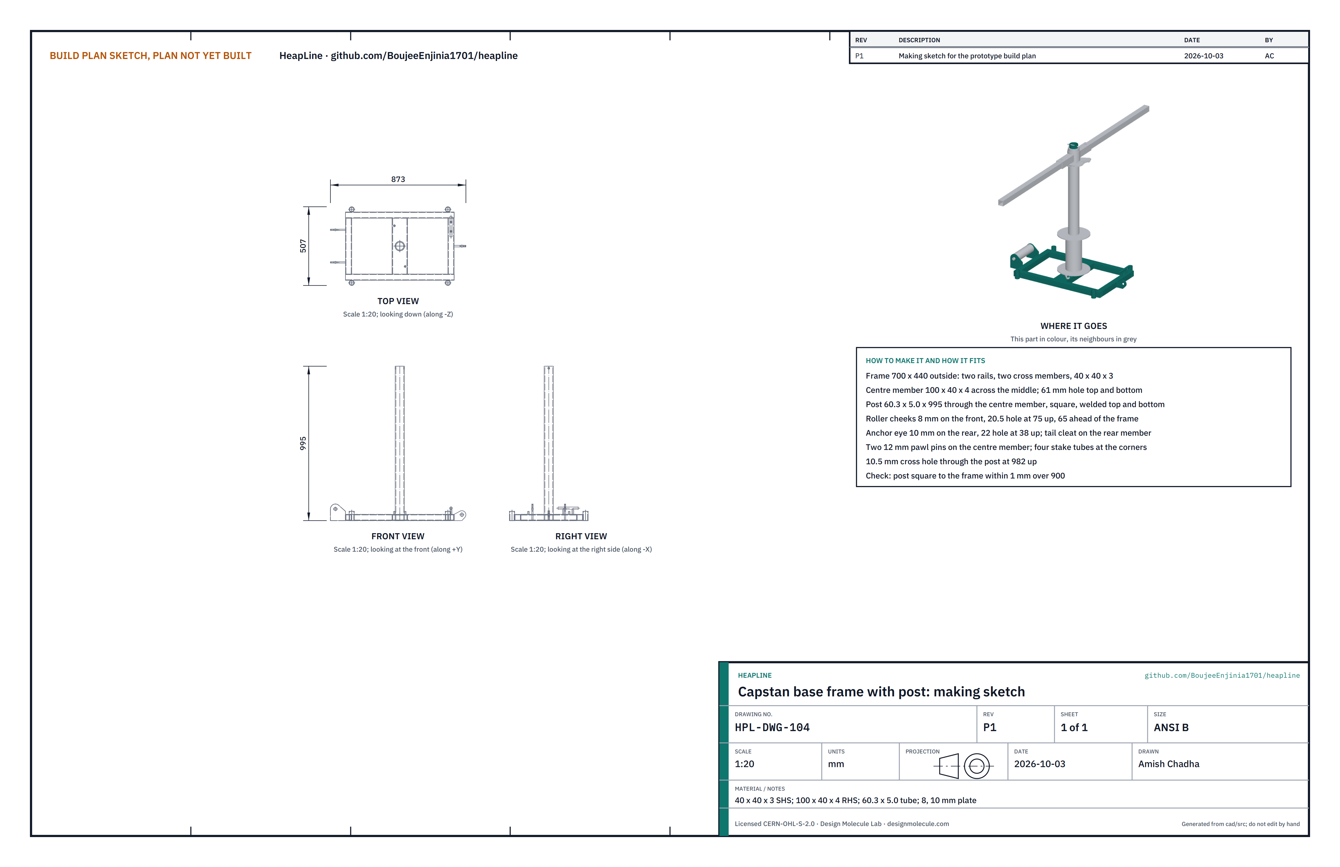
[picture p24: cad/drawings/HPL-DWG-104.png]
Figure 8. Making sketch of the capstan base frame


*Figure 8. Capstan base frame making sketch (HPL-DWG-104).*

**What it is and what it is made from.** The welded base that carries everything else. 40 x 40 x 3 steel square tube; 100 x 40 x 4 rectangular tube; 60.3 x 5.0 tube; 8 and 10 mm plate; 33.7 x 3.2 tube; 12 and 16 mm bar.

**How to make it.**

1. Cut and weld a rectangular frame 700 long and 440 wide outside from the 40 tube.
2. Cut the 100 x 40 centre member to fit across the middle and drill a 61 mm hole through its top and bottom faces, centred.
3. Weld the centre member in. Push the 995 post through both holes until its foot is flush with the bottom face, check it square to the frame both ways, and weld it all round at the top and bottom faces.
4. Weld two 8 mm roller cheeks to the front member's outer face, 202 apart inside, with 20.5 holes 75 up and 65 ahead of the frame.
5. Weld the 10 mm anchor eye to the middle of the rear member's outer face, its 22 hole 38 up and 50 behind the frame.
6. Weld the tail cleat (two 12 mm posts and a 16 mm horn) on the rear member, toward one side.
7. Weld two 12 mm pawl pins upright on the centre member at the positions on the sketch, and four stake tubes 60 long to the rail outsides at the corners.
8. Drill a 10.5 mm cross hole through the post 982 up.

**How it fits the parts next to it.**

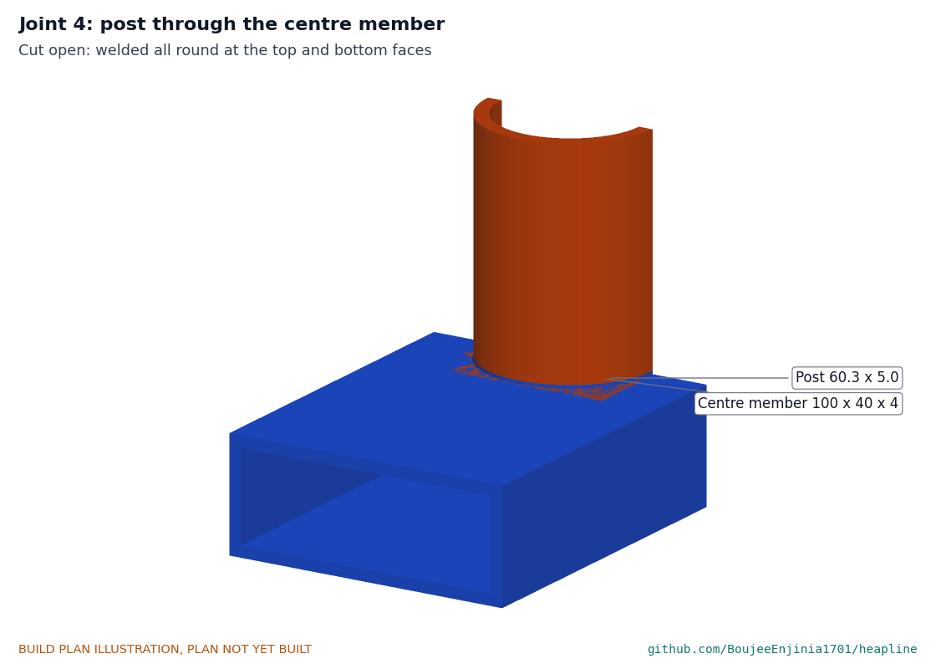
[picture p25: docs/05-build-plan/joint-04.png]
Figure 9. Joint 4: post through the centre member


*Figure 9. Joint 4, cut open. The post passes through both faces of the centre member and is welded at each; the two welds carry the bending from the rope.*

**Check before moving on.** The post is square to the frame within 1 mm over 900; the frame sits flat without rocking.

### 3.5 Drum with holding ratchet

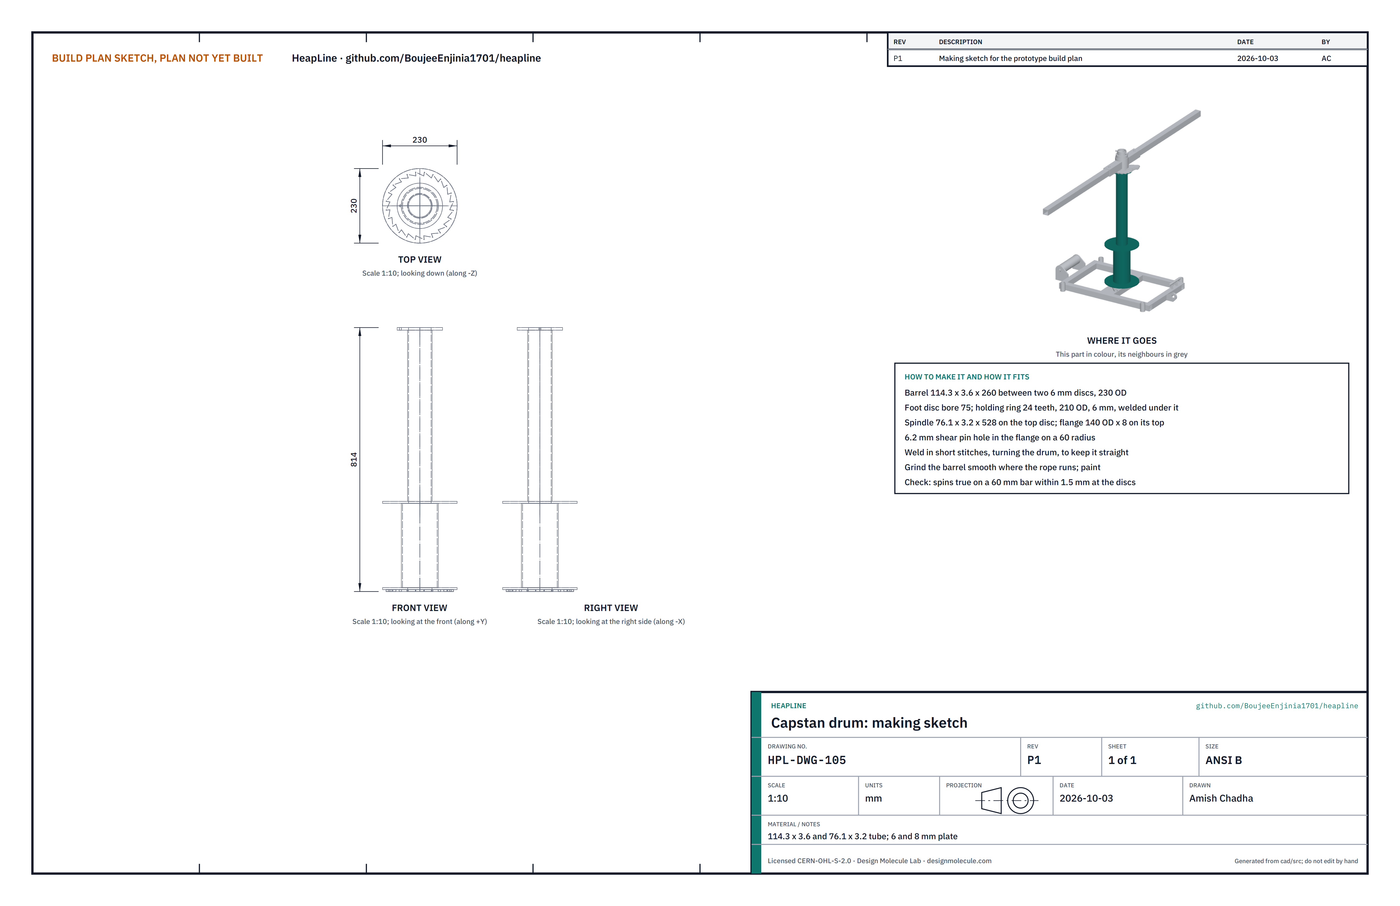
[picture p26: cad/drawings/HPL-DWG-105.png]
Figure 10. Making sketch of the drum


*Figure 10. Drum making sketch (HPL-DWG-105).*

**What it is and what it is made from.** The drum the rope wraps round, with its holding ring and the spindle that carries it up to the head. 114.3 x 3.6 and 76.1 x 3.2 tube; 6 and 8 mm plate, the ring profile cut.

**How to make it.**

1. Have the holding ring (24 teeth, 210 outside, 75 bore, 6 mm) and two 230 discs profile cut; bore the foot disc 75 and the top disc 70.
2. Cut the barrel 260 long and the spindle 528 long.
3. Weld the discs to the barrel ends, square, then the spindle centred on the top disc and the 140 x 8 flange on the spindle top.
4. Weld the ring under the foot disc, teeth facing the way the sketch shows.
5. Drill the 6.2 shear pin hole through the flange on a 60 radius.
6. Weld in short stitches, turning the drum between them, and grind the barrel smooth where the rope runs.

**How it fits the parts next to it.**

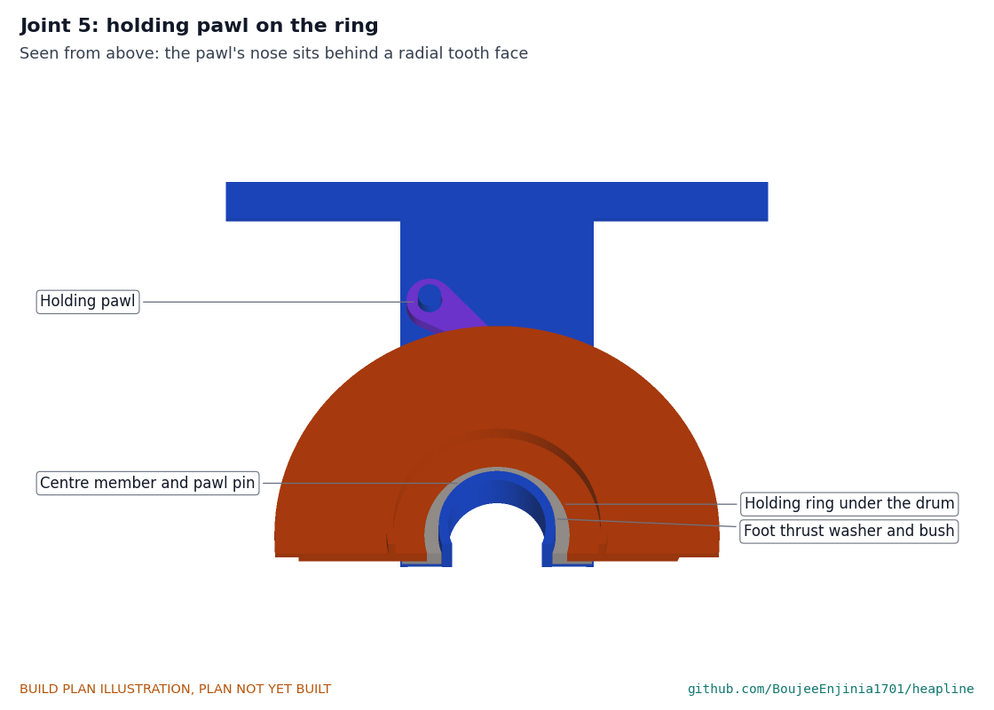
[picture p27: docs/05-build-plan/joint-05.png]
Figure 11. Joint 5: holding pawl on the ring


*Figure 11. Joint 5, seen from above. Each holding pawl's nose drops behind a radial tooth face, so the drum cannot turn back.*

**Check before moving on.** On a 60 mm bar the drum spins true within 1.5 mm at the discs.

### 3.6 Drive ratchet wheel

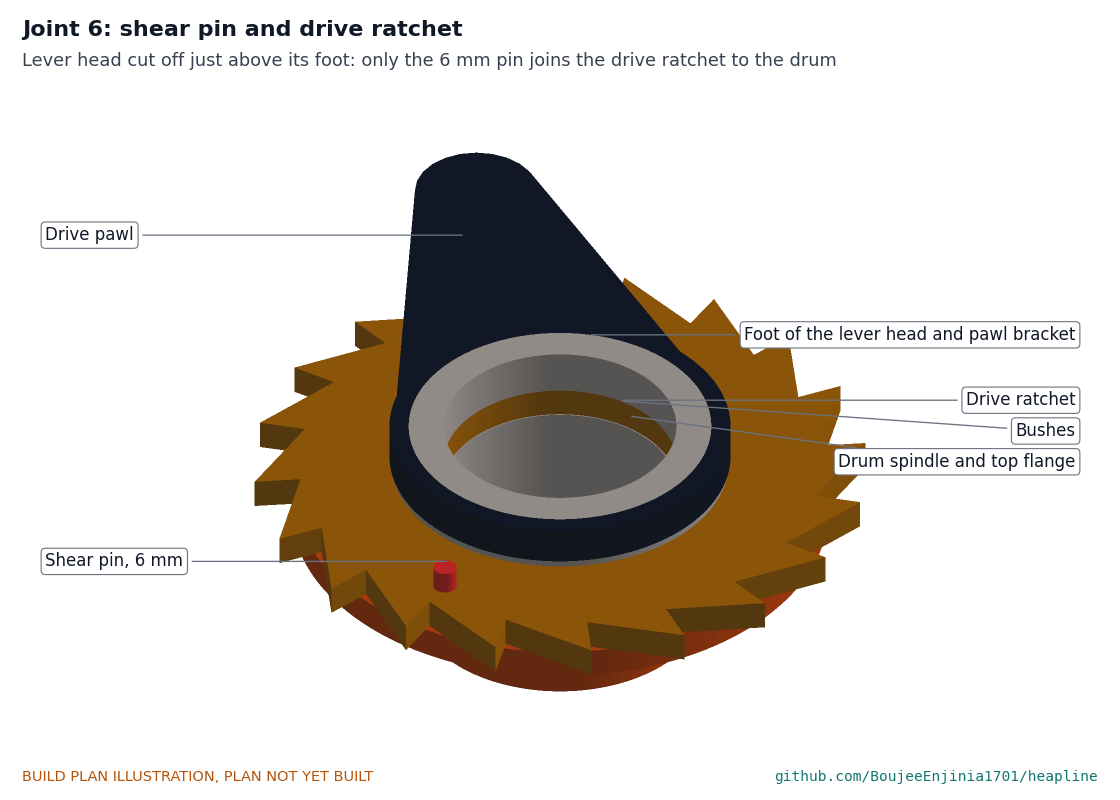
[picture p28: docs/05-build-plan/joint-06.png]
Figure 12. Joint 6: shear pin and drive ratchet


*Figure 12. Joint 6, cut open. The drive ratchet sits on the drum's top flange and is joined to it only by the 6 mm shear pin; the lever head turns on its own bush above.*

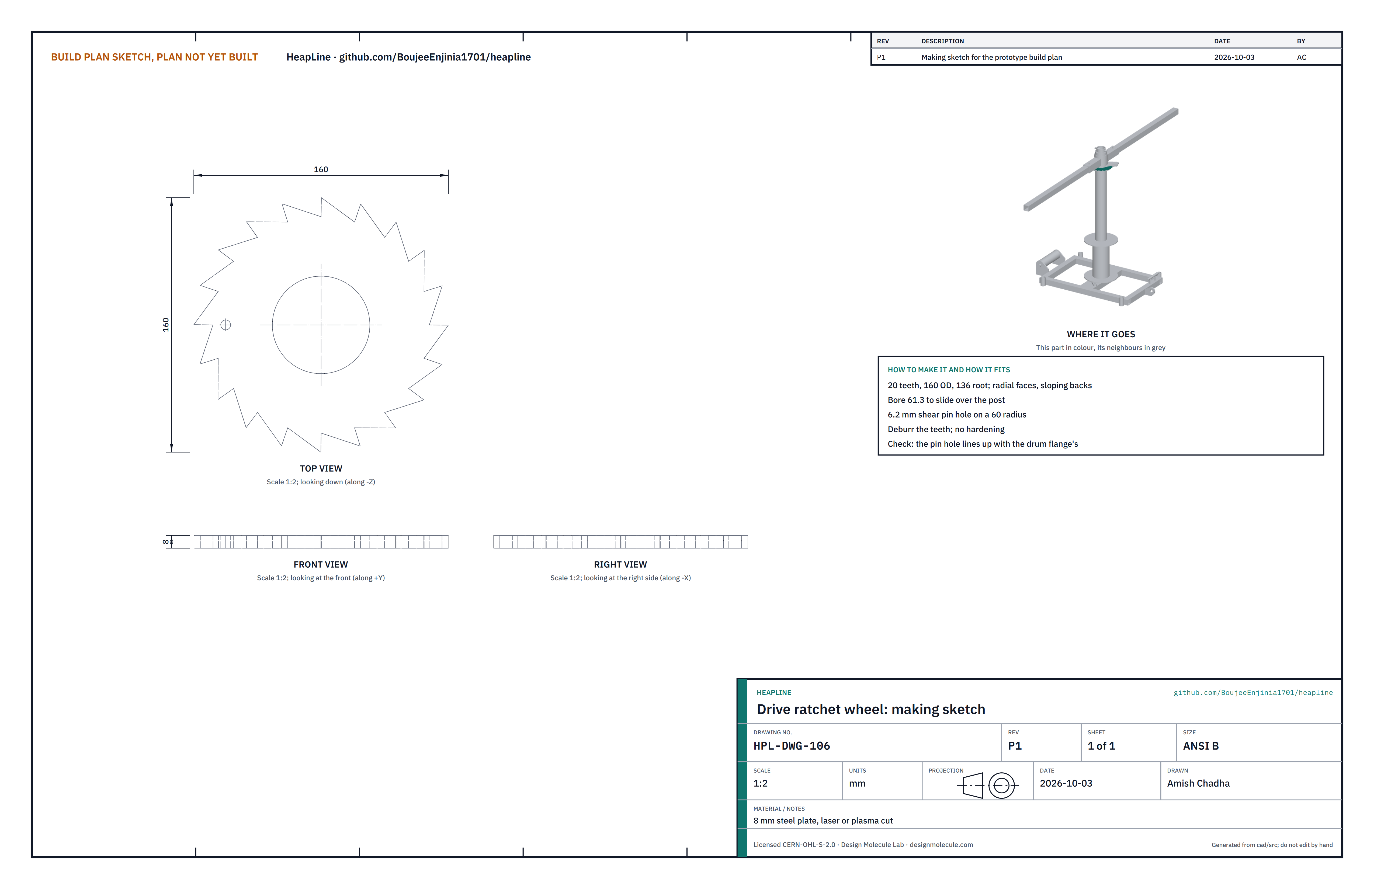
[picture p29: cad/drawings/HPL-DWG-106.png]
Figure 13. Making sketch of the drive ratchet


*Figure 13. Drive ratchet making sketch (HPL-DWG-106).*

**What it is and what it is made from.** The wheel the drive pawl pushes. 8 mm steel plate, profile cut: 20 teeth, 160 outside, bore 61.3.

**How to make it.** Have it profile cut; deburr the teeth; drill the 6.2 shear pin hole on a 60 radius, matched to the drum flange. Do not harden it.

**Check before moving on.** It slides over the post; its pin hole lines up with the flange's.

### 3.7 Lever head

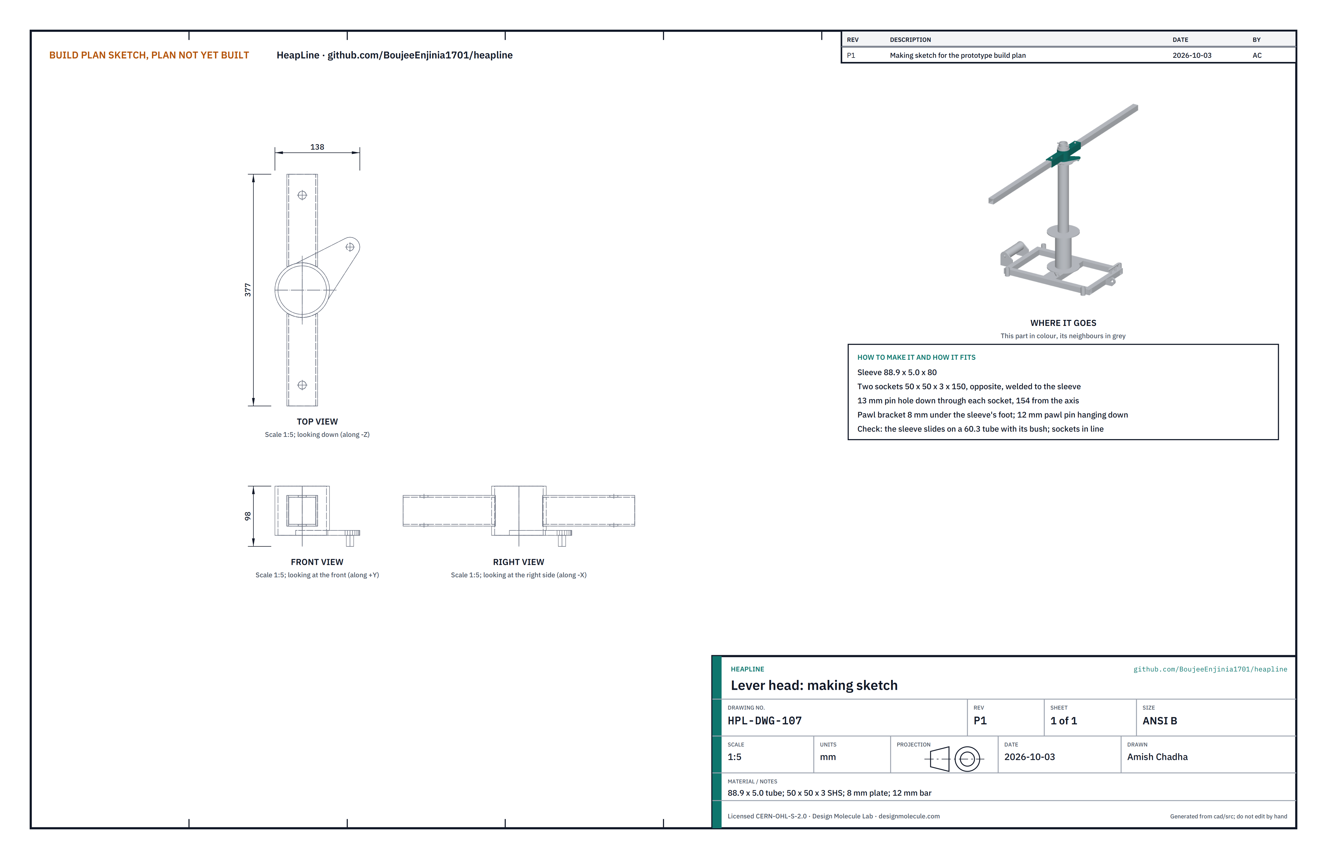
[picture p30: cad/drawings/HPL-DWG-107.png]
Figure 14. Making sketch of the lever head


*Figure 14. Lever head making sketch (HPL-DWG-107).*

**What it is and what it is made from.** The part the bars plug into, carrying the drive pawl. 88.9 x 5.0 tube 80 long; two 50 x 50 x 3 tube sockets 150 long; 8 mm plate; 12 mm bar.

**How to make it.**

1. Saddle the inner end of each socket to the sleeve and weld them on opposite sides, in line.
2. Drill a 13 hole down through each socket, 154 from the axis.
3. Weld the 8 mm pawl bracket under the sleeve's foot and the 12 mm pawl pin hanging down from it.

**How it fits the parts next to it.**

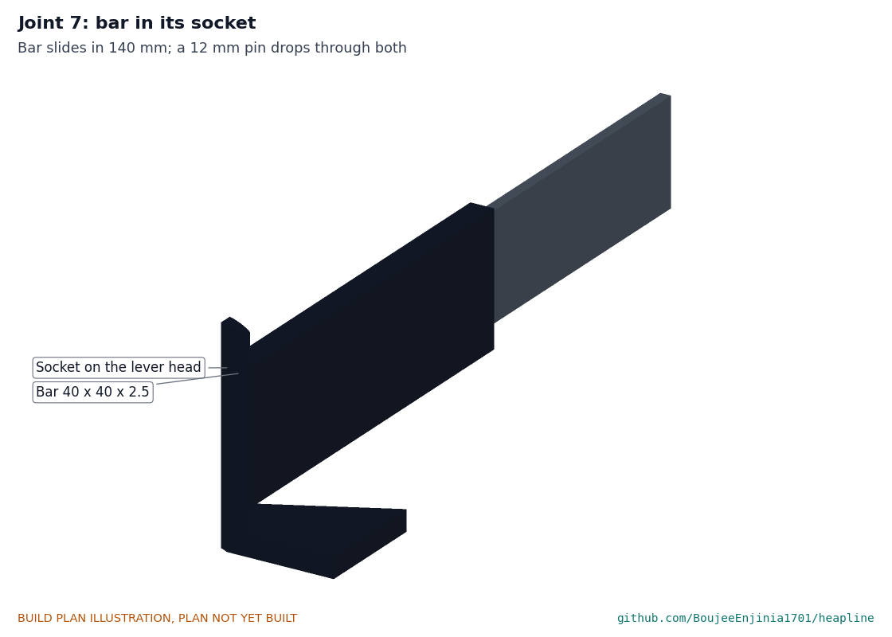
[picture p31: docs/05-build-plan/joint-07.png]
Figure 15. Joint 7: bar in its socket


*Figure 15. Joint 7. Each bar slides 140 into its socket; a 12 mm pin drops through both.*

**Check before moving on.** With its bush pressed in, the sleeve slides on a 60.3 tube; the sockets are in line within 2 degrees.

### 3.8 Pawls (make 3)

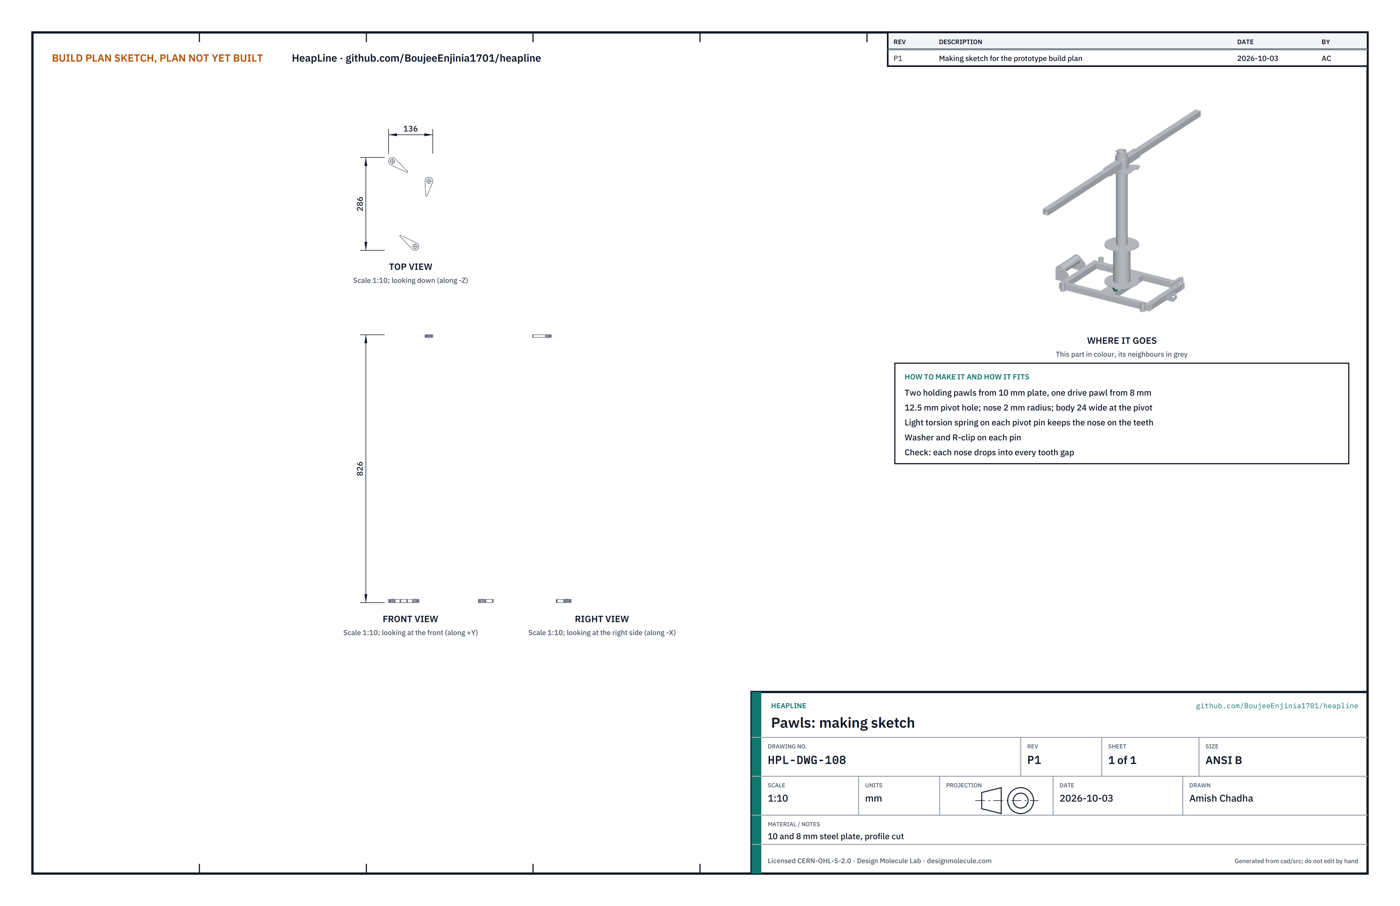
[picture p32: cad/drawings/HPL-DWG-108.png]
Figure 16. Making sketch of the pawls


*Figure 16. Pawls making sketch (HPL-DWG-108).*

**What it is and what it is made from.** Two holding pawls from 10 mm plate and one drive pawl from 8 mm plate, profile cut, with 12.5 mm pivot holes; a light torsion spring for each.

**How to make it.** Have them profile cut; break the edges; check the noses are crisp.

**How it fits the parts next to it.** See Figures 11 and 12: each pawl hangs on its 12 mm pin with its spring, a washer and an R-clip, its nose on the teeth.

**Check before moving on.** Each nose drops into every tooth gap as the wheel is turned by hand.

### 3.9 Capstan bars and pins

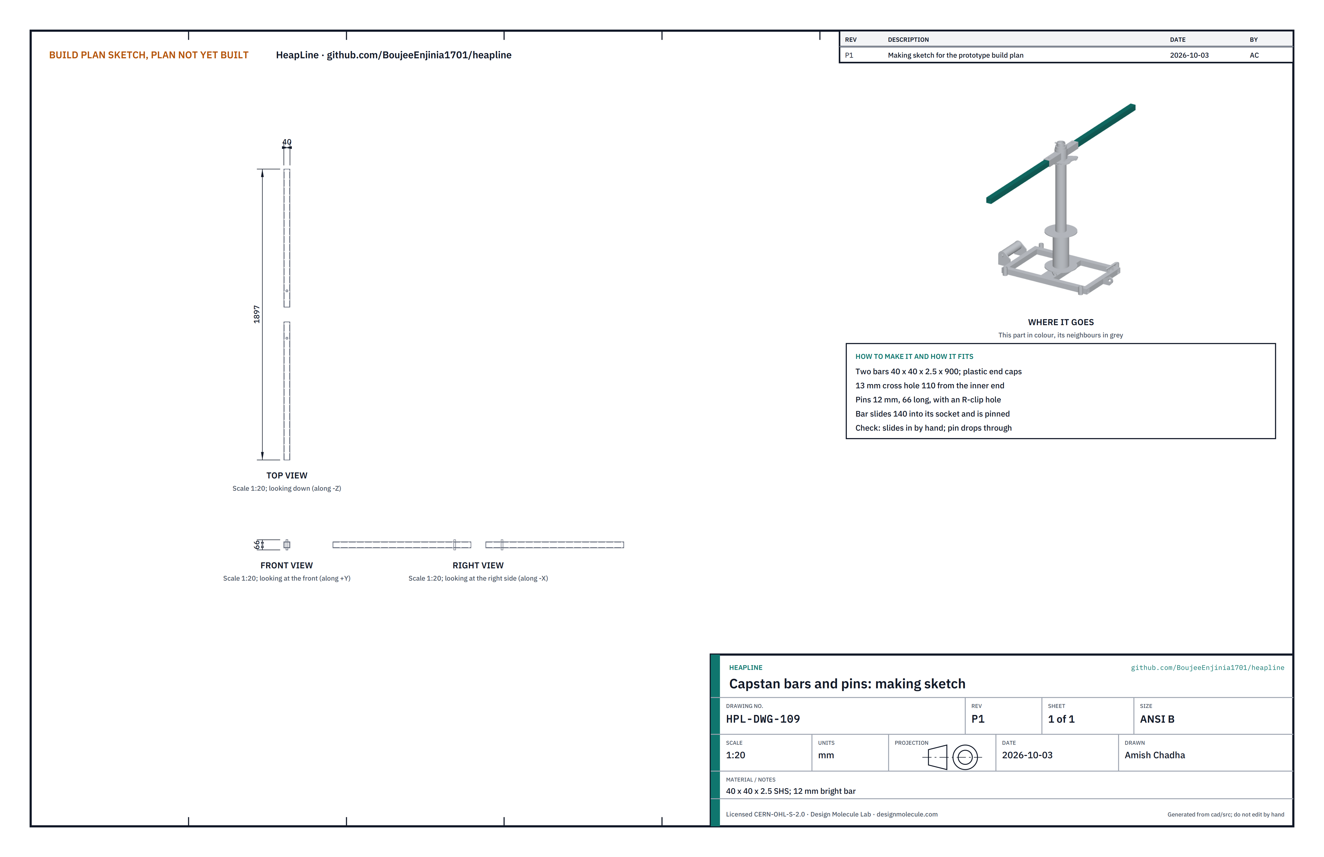
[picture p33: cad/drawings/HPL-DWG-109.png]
Figure 17. Making sketch of the bars


*Figure 17. Capstan bars making sketch (HPL-DWG-109).*

**What it is and what it is made from.** Two 900 long bars of 40 x 40 x 2.5 tube with 13 cross holes 110 from the inner end; two 12 mm pins 66 long with R-clips; plastic end caps.

**Check before moving on.** Each bar slides into either socket by hand and its pin drops through.

### 3.10 Bushes and thrust washers

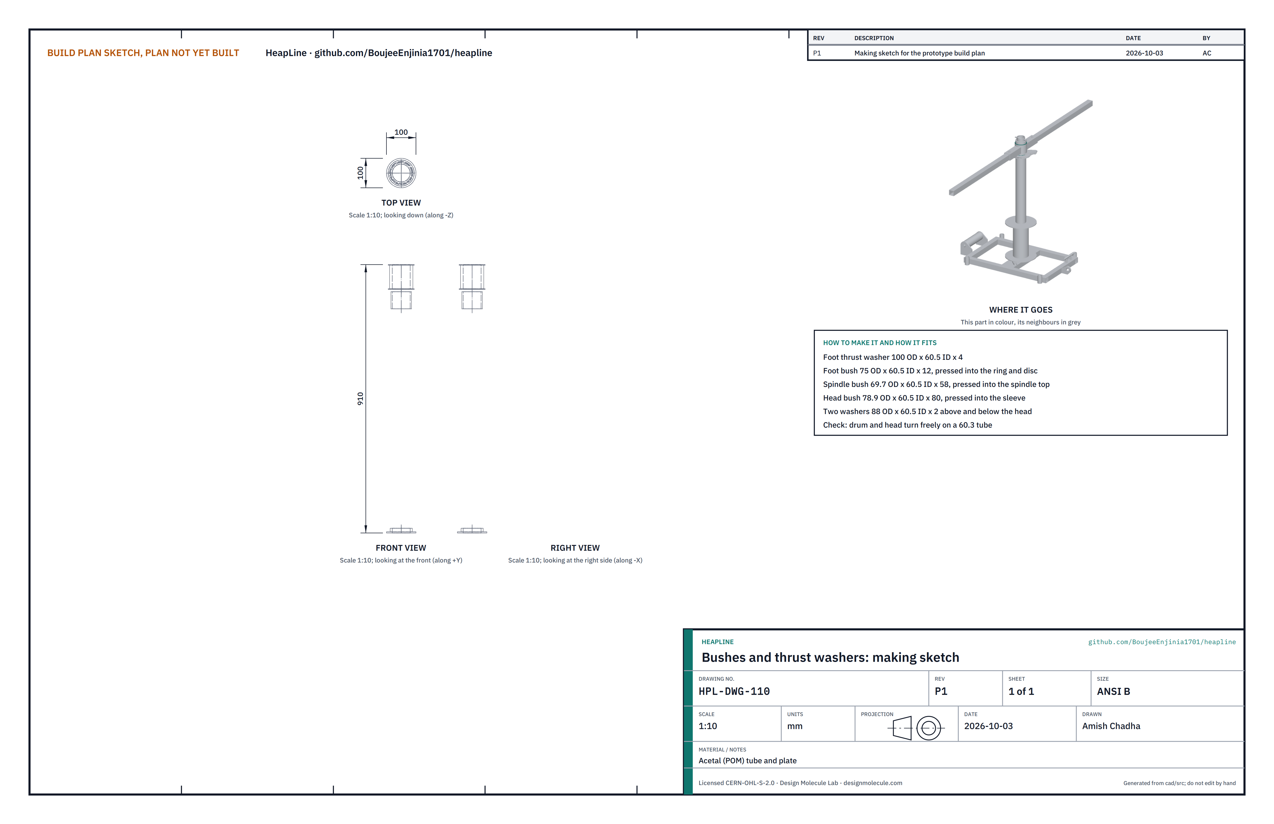
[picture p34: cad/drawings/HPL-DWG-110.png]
Figure 18. Making sketch of the bushes


*Figure 18. Bushes and thrust washers making sketch (HPL-DWG-110).*

**What it is and what it is made from.** Acetal (POM) bushes that the drum and head turn on: a foot thrust washer 100 x 60.5 x 4; a foot bush 75 x 60.5 x 12; a spindle bush 69.7 x 60.5 x 58; a head bush 78.9 x 60.5 x 80; two washers 88 x 60.5 x 2.

**How to make it.** Turn them from acetal stock. Press the foot bush into the ring and foot disc, the spindle bush into the spindle top and the head bush into the sleeve.

**Check before moving on.** Drum and head each turn freely by hand on a 60.3 tube.

### 3.11 Hold-down roller, pin and keeper

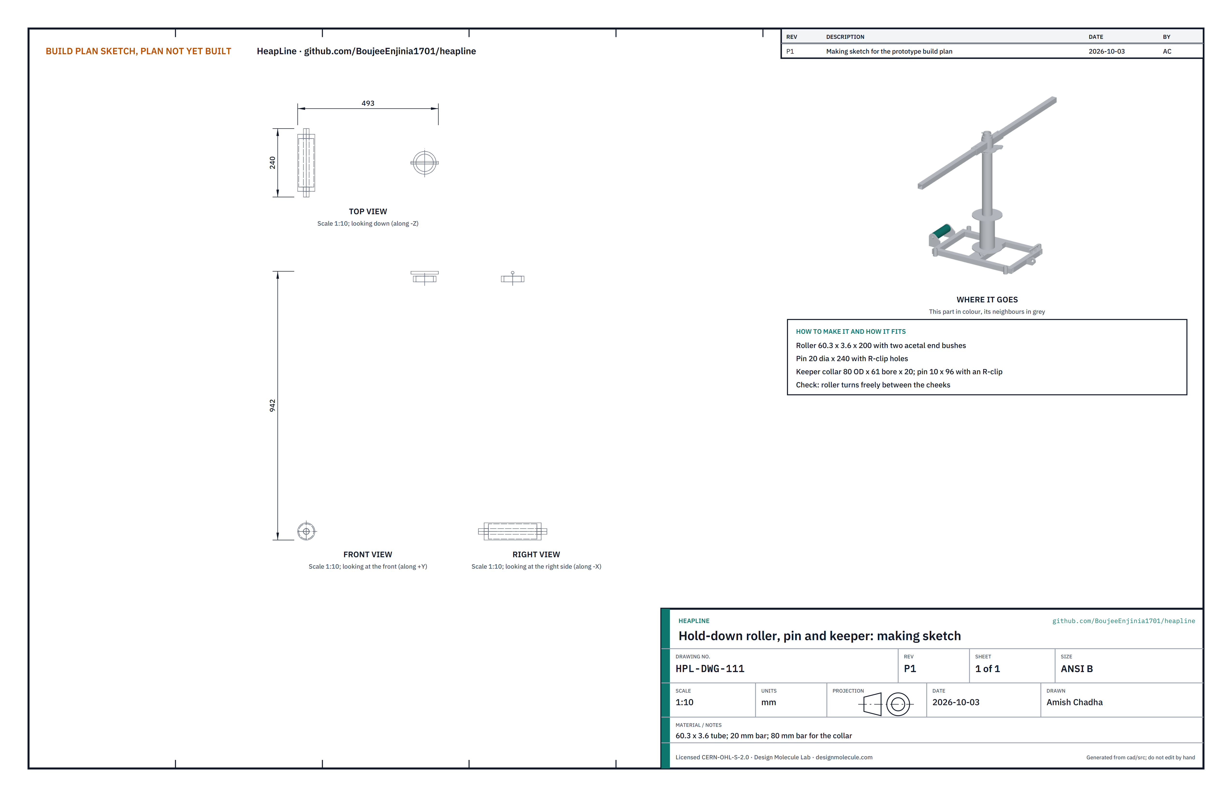
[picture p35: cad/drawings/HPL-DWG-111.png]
Figure 19. Making sketch of the roller, pin and keeper


*Figure 19. Hold-down roller, pin and keeper making sketch (HPL-DWG-111).*

**What it is and what it is made from.** The roller the rope runs under: 60.3 x 3.6 tube 200 long with acetal end bushes on a 20 mm pin 240 long. The keeper: a collar 80 x 61 x 20 and a 10 mm pin 96 long, both with R-clips.

**How it fits the parts next to it.**

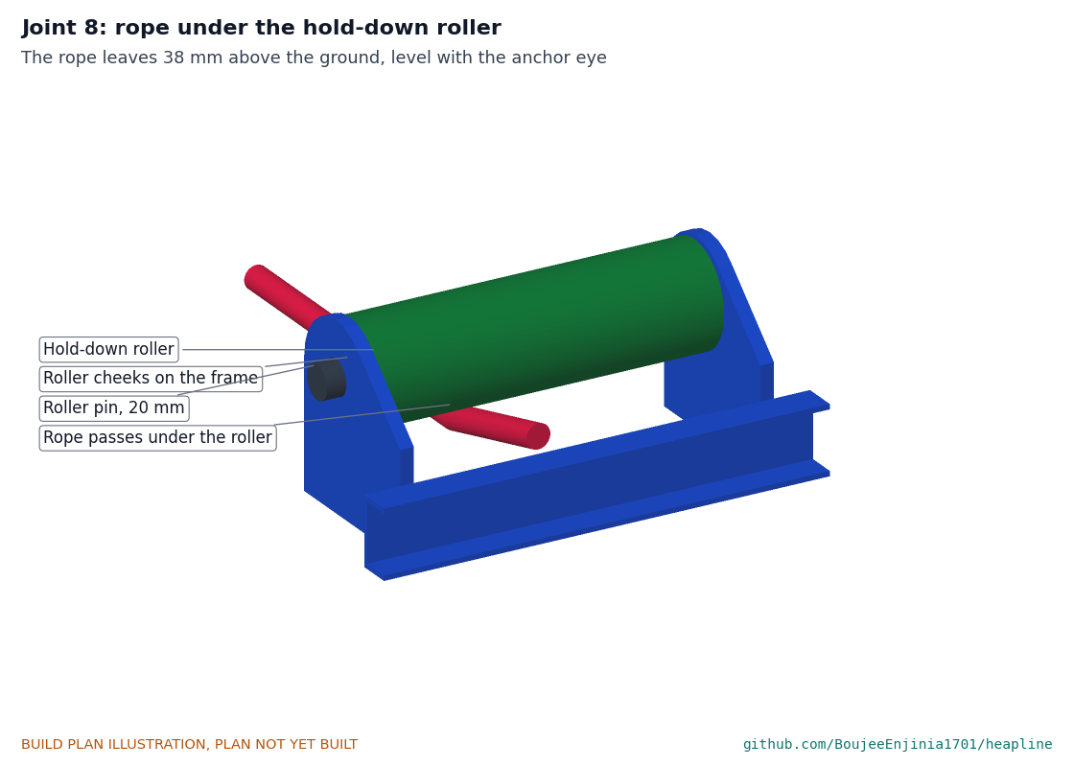
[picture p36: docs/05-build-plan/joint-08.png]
Figure 20. Joint 8: rope under the hold-down roller


*Figure 20. Joint 8. The rope comes down from the drum and passes under the roller, leaving 38 mm above the ground, level with the anchor eye.*

**Check before moving on.** The roller turns freely between the cheeks.

### 3.12 Ground stakes (make 4)

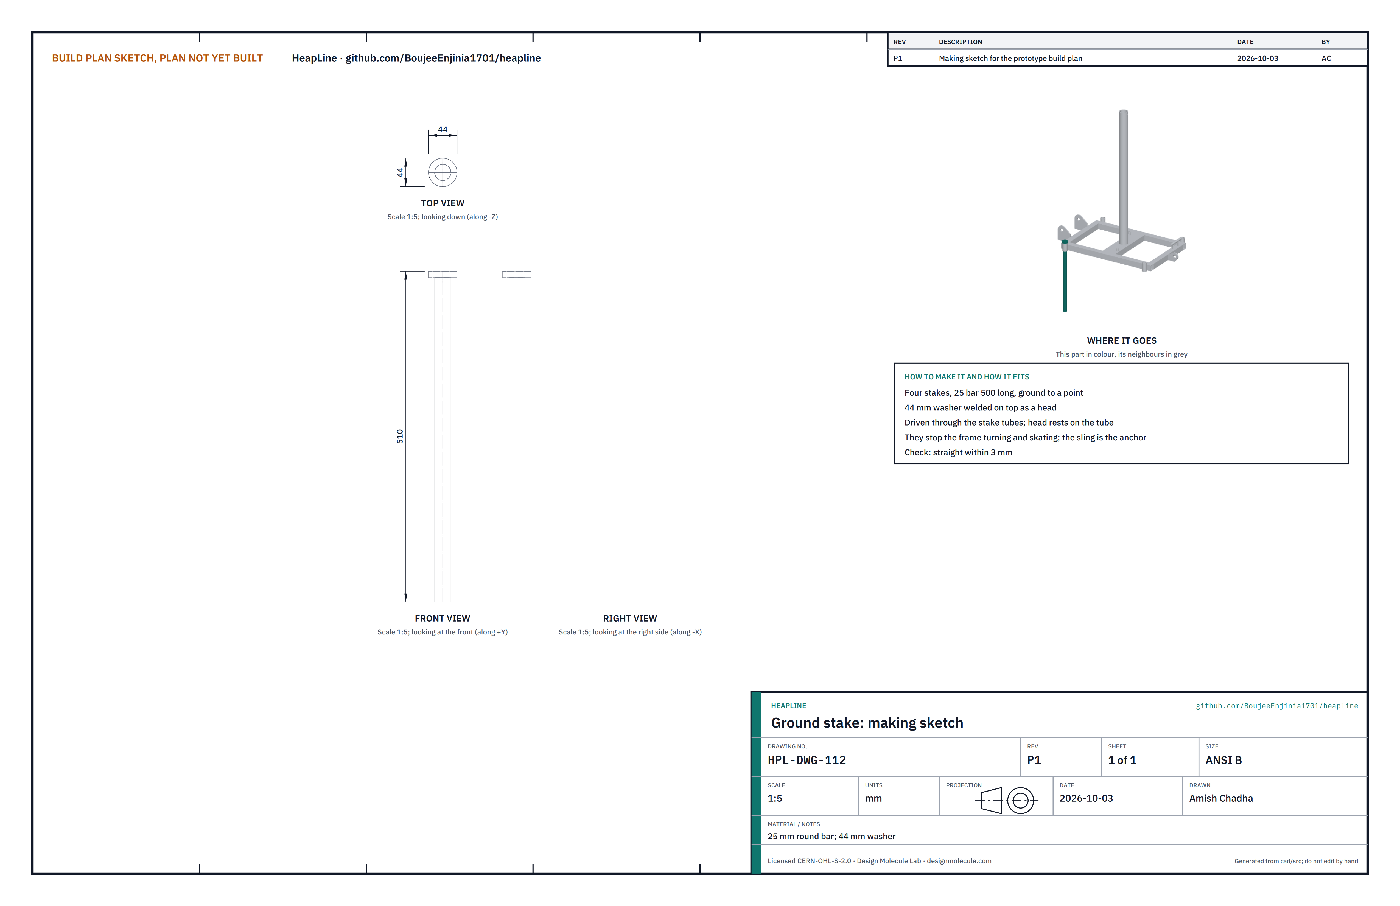
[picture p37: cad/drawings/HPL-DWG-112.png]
Figure 21. Making sketch of a ground stake


*Figure 21. Ground stake making sketch (HPL-DWG-112).*

**What it is and what it is made from.** 25 mm round bar 500 long, ground to a point, with a 44 mm washer welded on top as a head. Driven through the stake tubes until the heads rest on them. They stop the frame turning against the pawls; they are not the anchor.

**How it fits the parts next to it.**

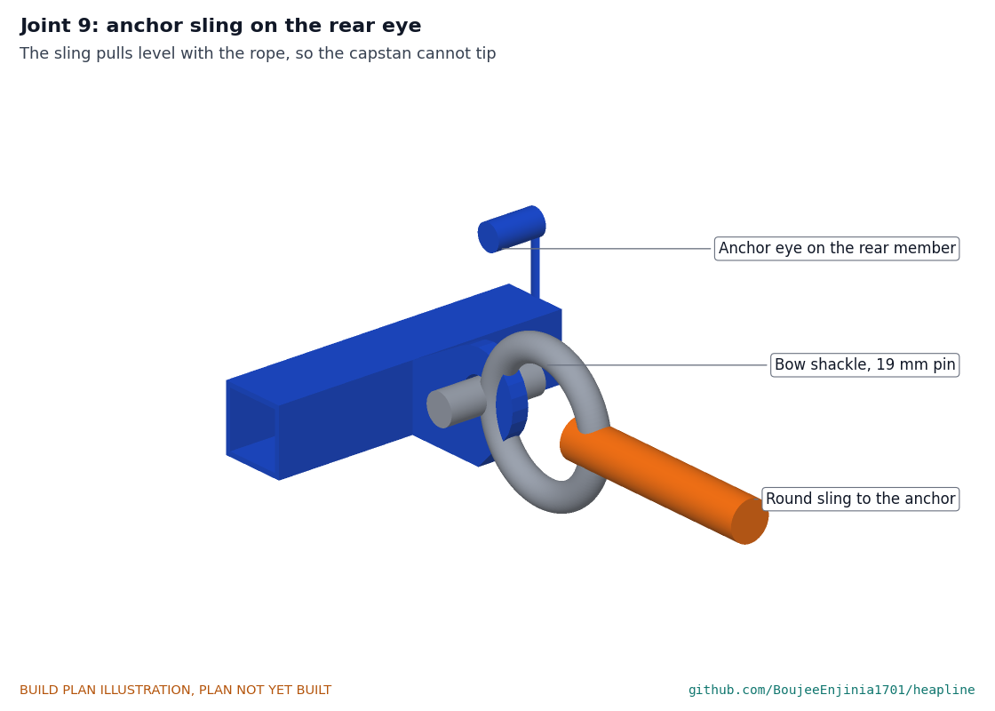
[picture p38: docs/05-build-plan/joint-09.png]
Figure 22. Joint 9: anchor sling on the rear eye


*Figure 22. Joint 9. A bow shackle's 19 mm pin goes through the 22 mm hole in the anchor eye; the round sling runs from the shackle to the anchor, level with the rope.*

**Check before moving on.** Each stake is straight within 3 mm.

### 3.13 Sheet clamp

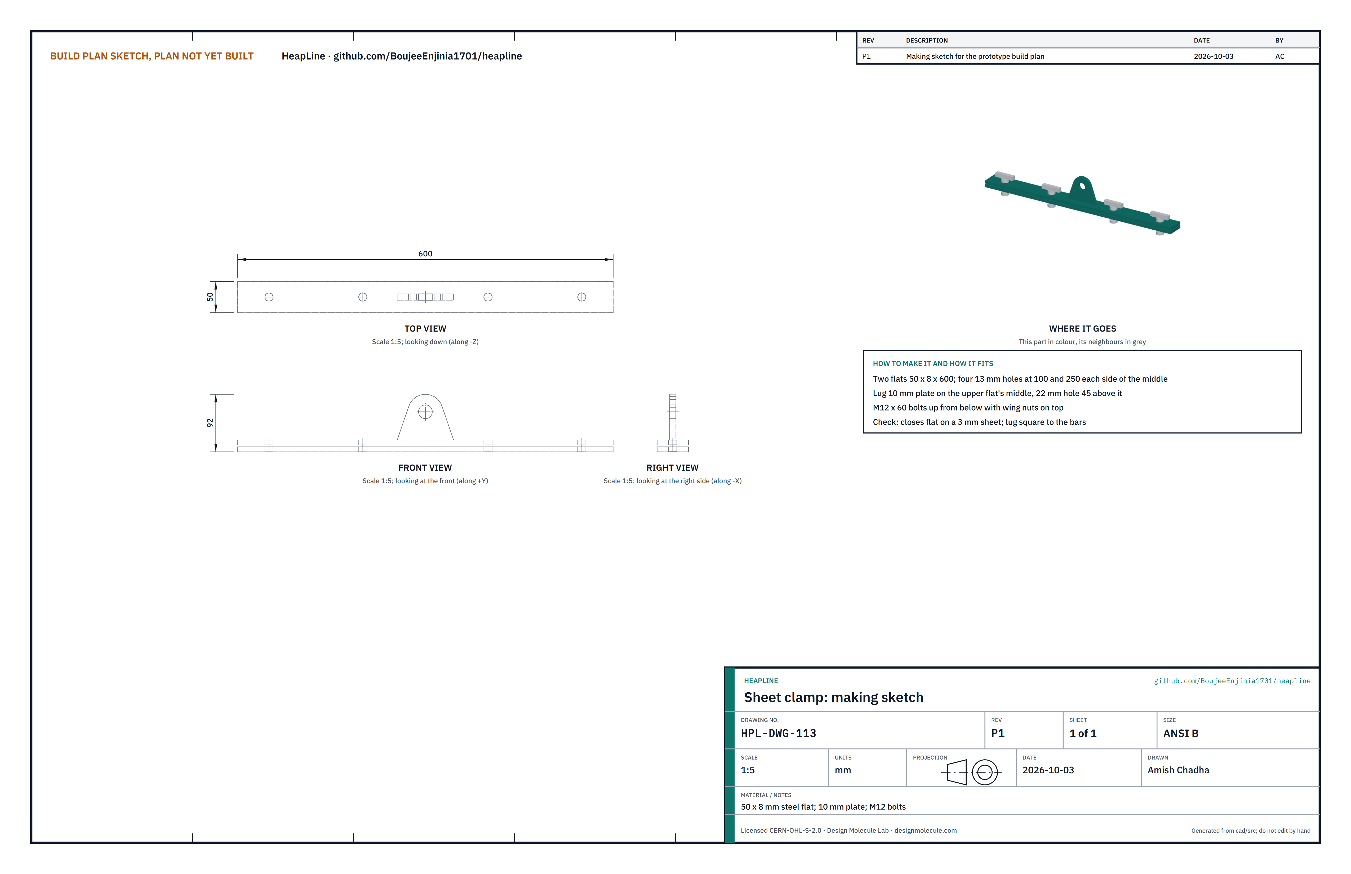
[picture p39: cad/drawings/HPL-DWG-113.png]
Figure 23. Making sketch of the sheet clamp


*Figure 23. Sheet clamp making sketch (HPL-DWG-113).*

**What it is and what it is made from.** Two 50 x 8 steel flats 600 long; a 10 mm lug plate; four M12 x 60 bolts with wing nuts and washers.

**How to make it.**

1. Clamp the two flats together and drill four 13 holes through both, at 100 and 250 each side of the middle.
2. Weld the lug to the middle of the upper flat, square, its 22 hole 45 above the flat.

**How it fits the parts next to it.**

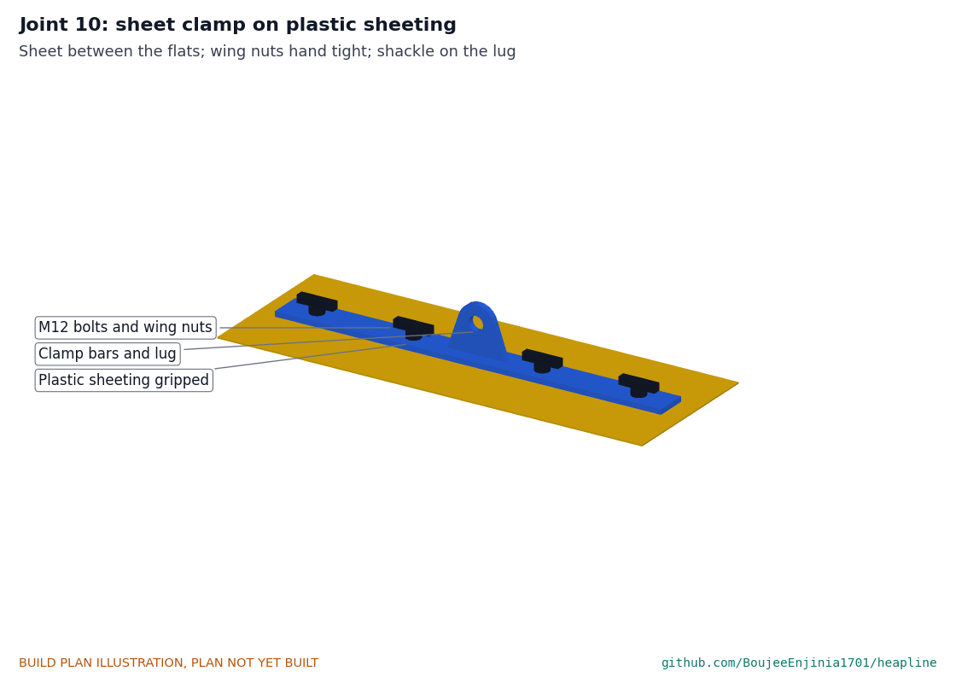
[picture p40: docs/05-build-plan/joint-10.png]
Figure 24. Joint 10: sheet clamp on plastic sheeting


*Figure 24. Joint 10. The sheeting lies between the flats; the bolts pass up through the sheet and the wing nuts are hand tight. The rope's shackle goes on the lug.*

**Check before moving on.** The flats close flat on a 3 mm sheet.

### 3.14 Sheet stretcher

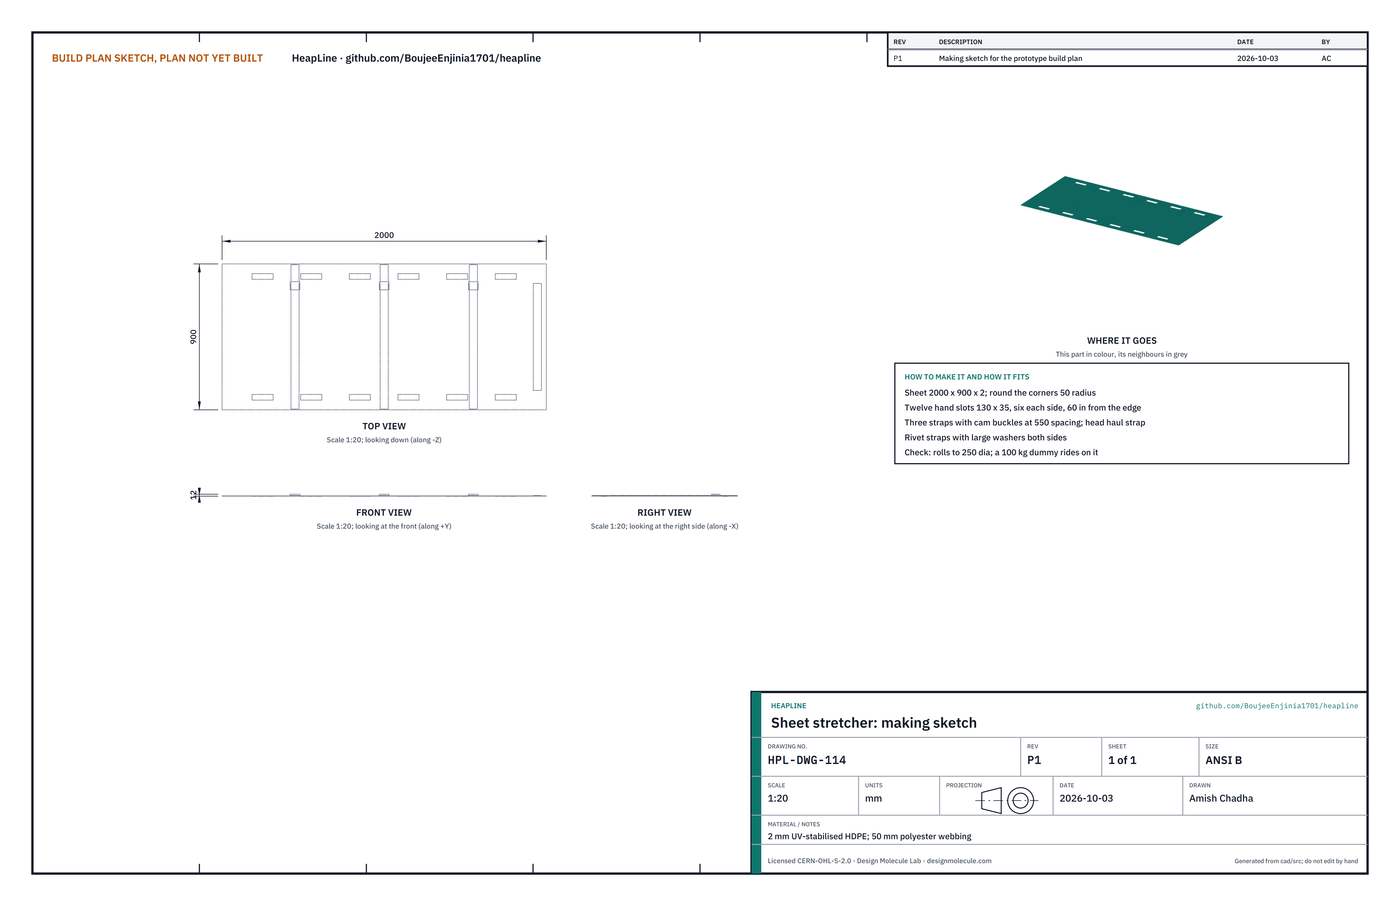
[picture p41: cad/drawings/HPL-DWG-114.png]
Figure 25. Making sketch of the sheet stretcher


*Figure 25. Sheet stretcher making sketch (HPL-DWG-114).*

**What it is and what it is made from.** 2 mm UV-stabilised HDPE sheet 2000 x 900; 50 mm polyester webbing; cam buckles; rivets with large washers.

**How to make it.**

1. Cut the sheet and round the corners to 50 radius.
2. Cut twelve hand slots 130 x 35, six along each long edge, 60 in from the edge, and smooth their edges.
3. Rivet three straps across the sheet at 550 spacing, with a cam buckle on one end of each, and a haul strap across the head end.

**Check before moving on.** The sheet rolls to about 250 diameter and lies flat again.

### 3.15 Search crate body (and the capstan crate)

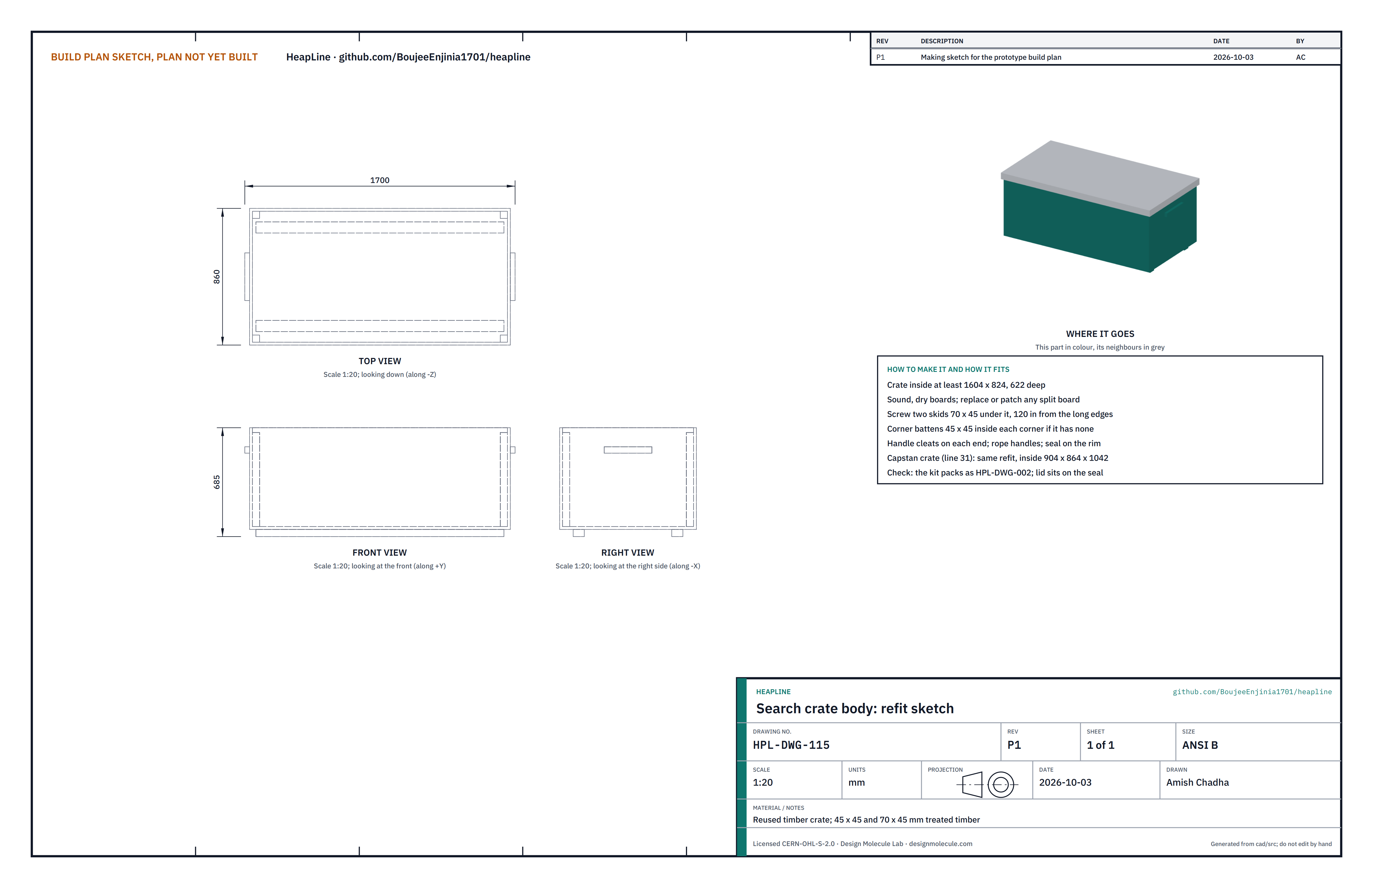
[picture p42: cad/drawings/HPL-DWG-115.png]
Figure 26. Refit sketch of the search crate body


*Figure 26. Search crate body refit sketch (HPL-DWG-115).*

**What it is and what it is made from.** The crate the search kit lives in at each shed. A reused timber shipping crate or lidded pallet box, sound and dry, at least 1604 long, 824 wide and 622 deep inside; 45 x 45 and 70 x 45 treated timber; screws and exterior paint. The host site also keeps a capstan crate, refitted the same way, at least 904 x 864 inside and 1042 deep. Where no crate can be had, a bought steel job box of at least the same inside size will do, at a higher cost.

**How to make it.**

1. Measure the crate inside. Patch or replace any split or rotten board.
2. Screw two skids under it, 120 in from the long edges, so it stands off the wet ground.
3. If it has no corner posts inside, glue and screw 45 x 45 battens into each corner.
4. Fix a hardwood handle cleat to each end and thread a rope handle through it.
5. Fix the EPDM seal strip round the top rim; prime and paint every face.

**Check before moving on.** The kit packs as drawn in HPL-DWG-002 with the lid shut.

### 3.16 Search crate lid

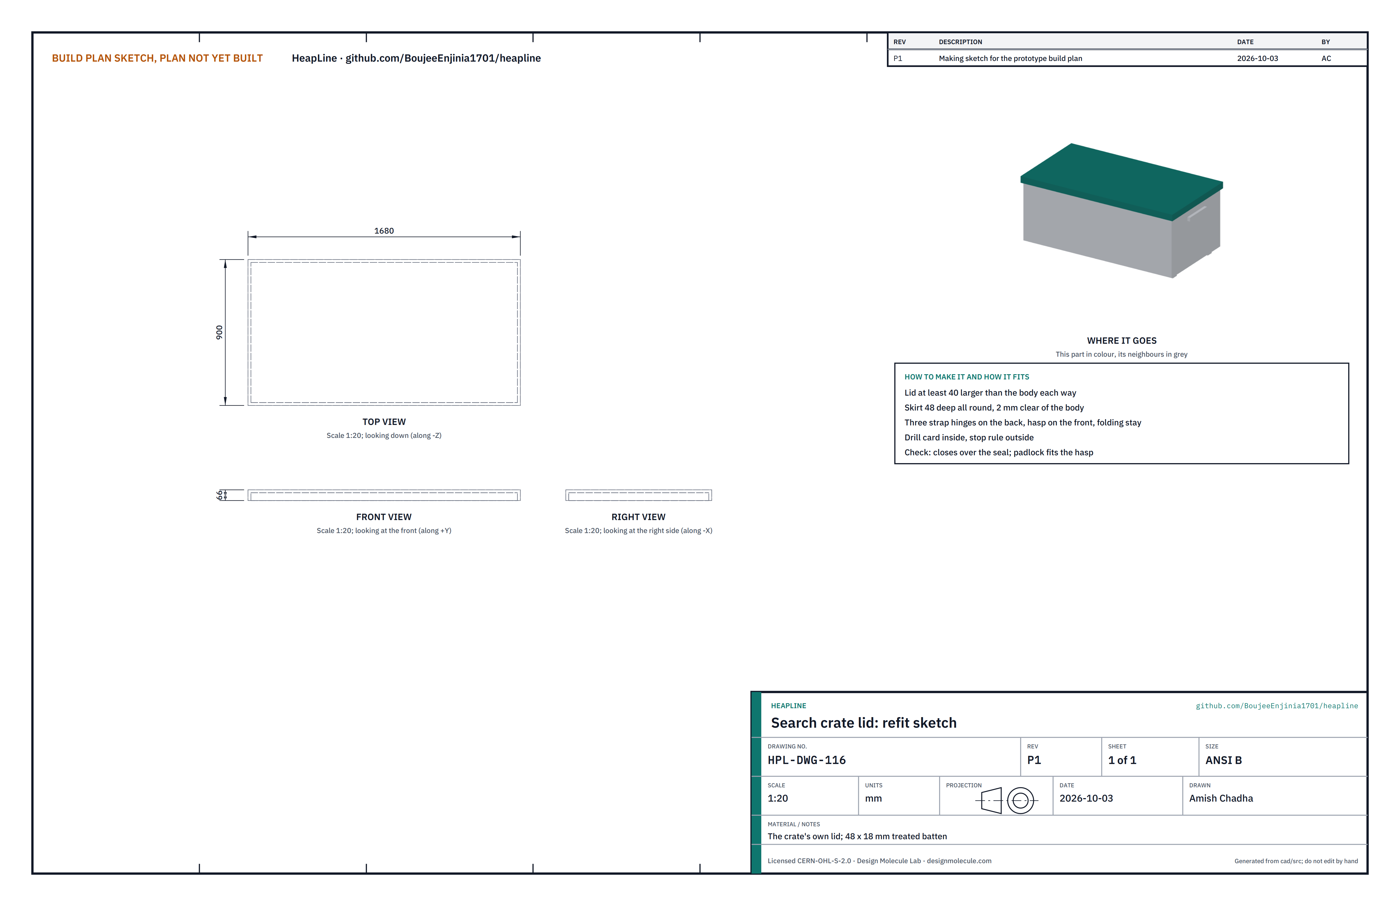
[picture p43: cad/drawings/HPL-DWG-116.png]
Figure 27. Refit sketch of the search crate lid


*Figure 27. Search crate lid refit sketch (HPL-DWG-116).*

**What it is and what it is made from.** The crate's own lid, with a skirt of 48 x 18 treated batten screwed under its edges all round, 2 clear of the body.

**How to make it.** Screw the skirt under the lid's edges; paint; fit three strap hinges on the back, the hasp on the front and a folding steel stay; apply the drill card inside and the stop rule outside. Refit the capstan crate's lid the same way.

**How it fits the parts next to it.**

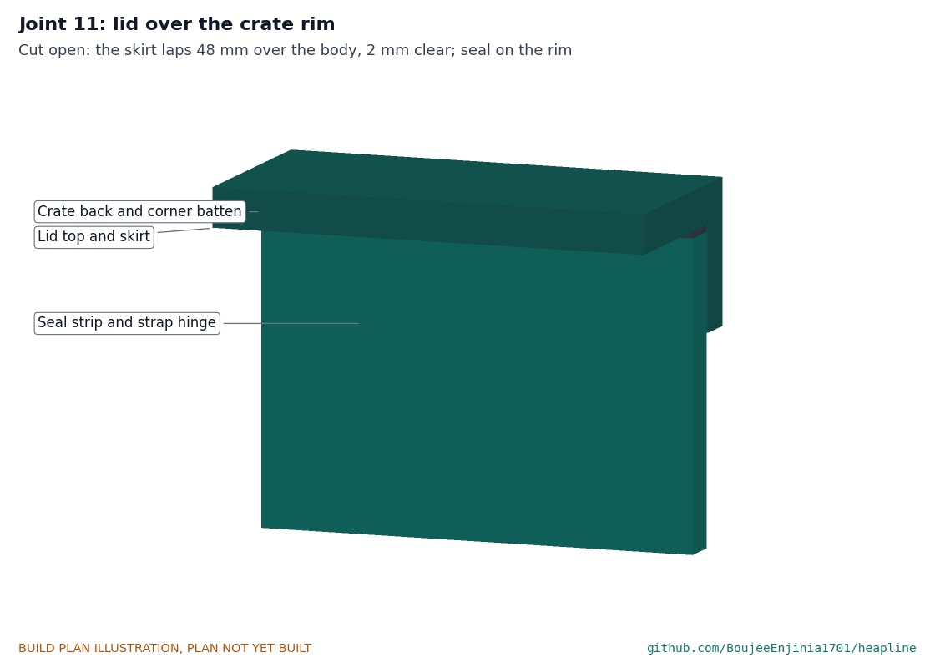
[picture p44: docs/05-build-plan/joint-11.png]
Figure 28. Joint 11: lid over the crate rim


*Figure 28. Joint 11, cut open at the back. The lid sits on the seal and its skirt laps 48 down over the body, so rain runs off outside.*

**Check before moving on.** The lid closes evenly on the seal and the padlock fits the hasp.

### 3.17 Bought components

Buy to specification, not brand. Line numbers are those of the bill of materials.

- **Crate hardware (lines 3 and 31).** For each crate: three 300 galvanised strap hinges, a heavy hasp and staple, a shrouded weatherproof combination padlock, a folding steel lid stay, 5.0 m of 10 x 3 EPDM seal, rope for handles.
- **Probe pins (line 7).** R-clips for a 5 mm hole on short lanyards.
- **Shovels (line 8).** Four long-handled round-point steel shovels about 1.45 m long.
- **Shear pins (line 18).** 6 mm S275 bright mild steel bar cut 32 long with split pins; never hardened steel and never a bolt.
- **Club hammer (line 19).** 1.8 kg.
- **Rope (line 20).** 30 m of 14 mm polyester double braid, minimum breaking strength at least 40 kN, with one eye splice and thimble at the load end.
- **Slings and shackles (line 21).** Two polyester round slings WLL 2,000 kg (3 m and 2 m), three bow shackles WLL 2,000 kg with 19 mm pins, a tree protector strap.
- **Lookout kit, lighting, PPE, cards, bags, fasteners and paint (lines 24 to 30).** As listed in the bill of materials; the lamps take AA alkaline cells, and no lithium cells go in the crates. The PPE comes from the cooperative's own stock and is kept in its bag in the search crate.
- **Drill card (line 27).** Besides the stop rule, it carries two rules: the kit goes out in two waves (four people with the search kit first, then three with the capstan set from the host site), and the stretcher is hauled by four people whenever it crosses debris, by two only along the boards.

## 4. Putting it together

In each picture the parts already fitted are grey and the part being fitted is in colour, with an arrow showing the way it goes in. Steps 1 to 11 are done in the workshop; steps 12 to 15 are the drill on a practice heap that cannot move. Two people for the capstan steps.

### Step 1: bushes and washers onto the post

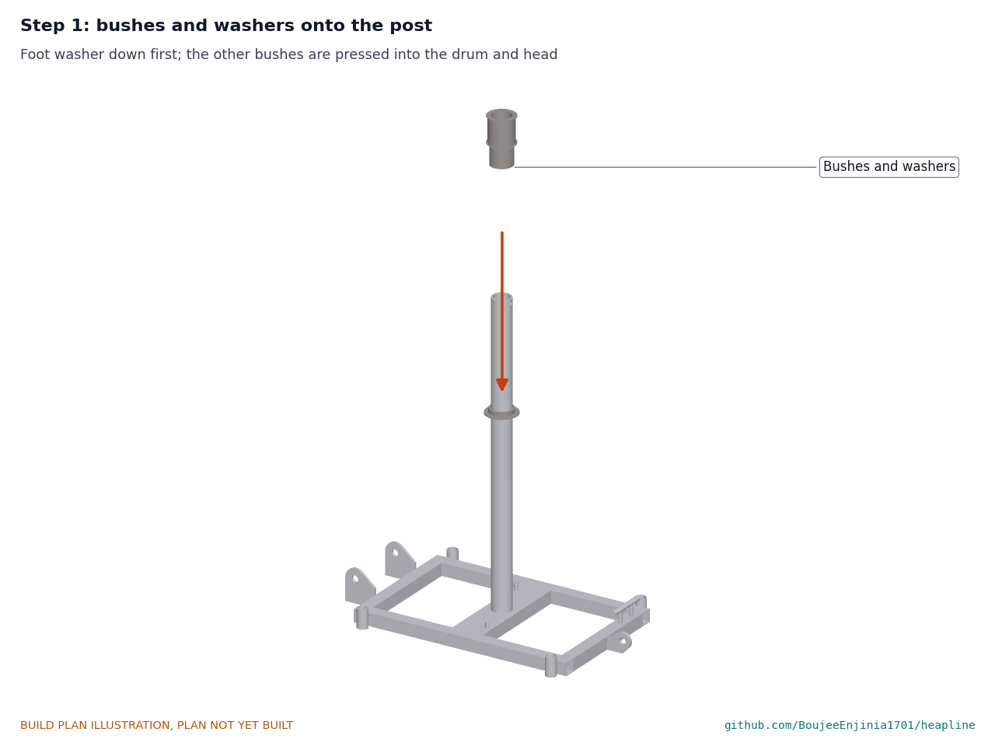
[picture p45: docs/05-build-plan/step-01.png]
Step 1


Drop the foot thrust washer over the post onto the centre member. The other bushes are already pressed into the drum and the head (section 3.10). Grease the post lightly.

### Step 2: lower the drum over the post

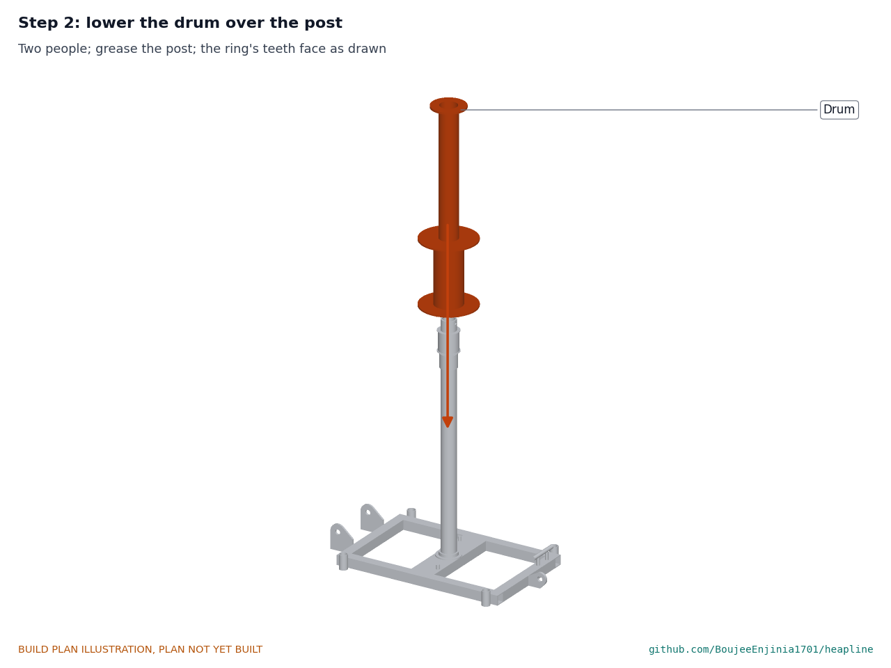
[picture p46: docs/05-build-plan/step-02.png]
Step 2


Two people lift the drum (11 kg) and lower it over the post until the ring sits on the thrust washer. It should turn freely by hand.

### Step 3: holding pawls onto their pins

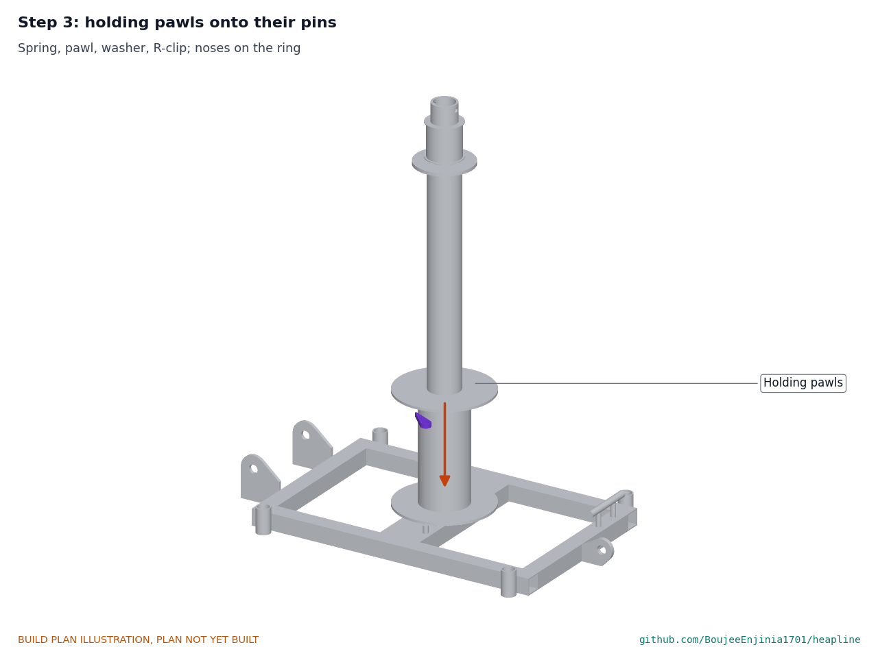
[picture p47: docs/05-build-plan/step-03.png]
Step 3


Fit each holding pawl's spring, then the pawl, a washer and an R-clip. Turn the drum in the haul direction: the pawls click. Try to turn it back: they hold.

### Step 4: drive ratchet and shear pin

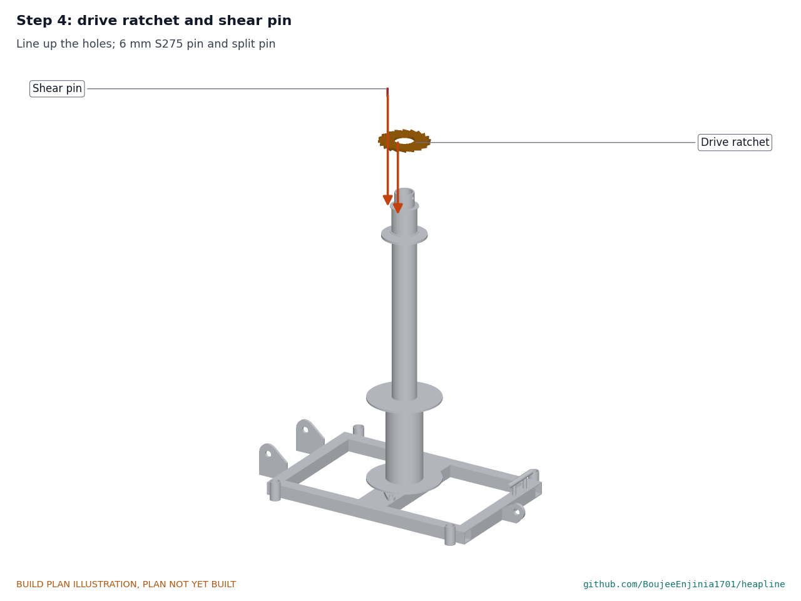
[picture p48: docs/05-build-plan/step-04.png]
Step 4


Slide the drive ratchet over the post onto the drum's top flange and line up the pin holes. Fit a 6 mm S275 shear pin and its split pin. Hang the spare pins on the tag chain on the frame.

### Step 5: lever head onto the post

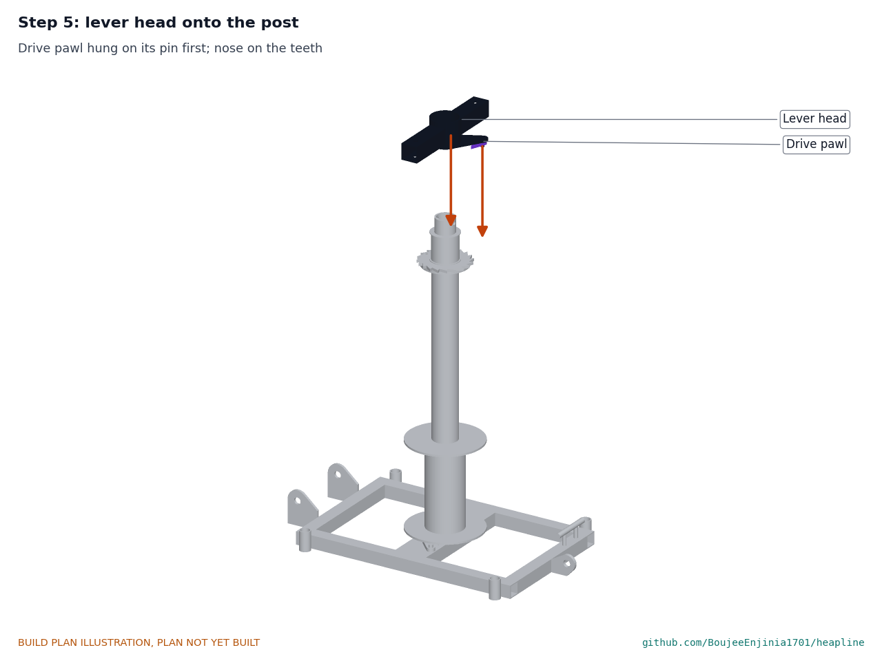
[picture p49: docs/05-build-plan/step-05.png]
Step 5


Hang the drive pawl and its spring on the head's pin. Fit the lower washer, then lower the head over the post until it rests on the ratchet, with the pawl's nose on the teeth.

### Step 6: keeper collar and pin

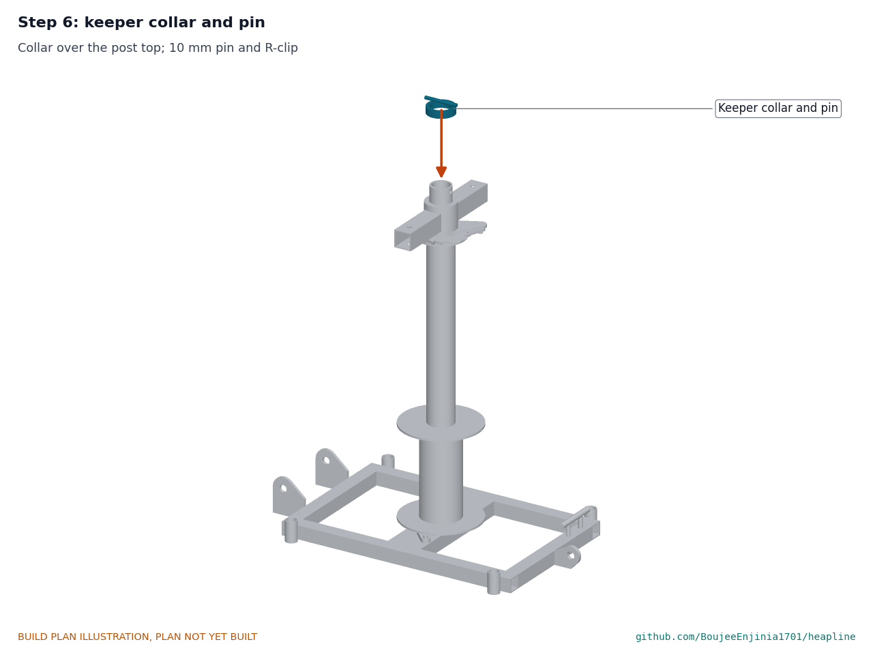
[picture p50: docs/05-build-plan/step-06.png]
Step 6


Fit the upper washer and the keeper collar over the post top and push the 10 mm pin through the cross hole; R-clip it.

### Step 7: hold-down roller between the cheeks

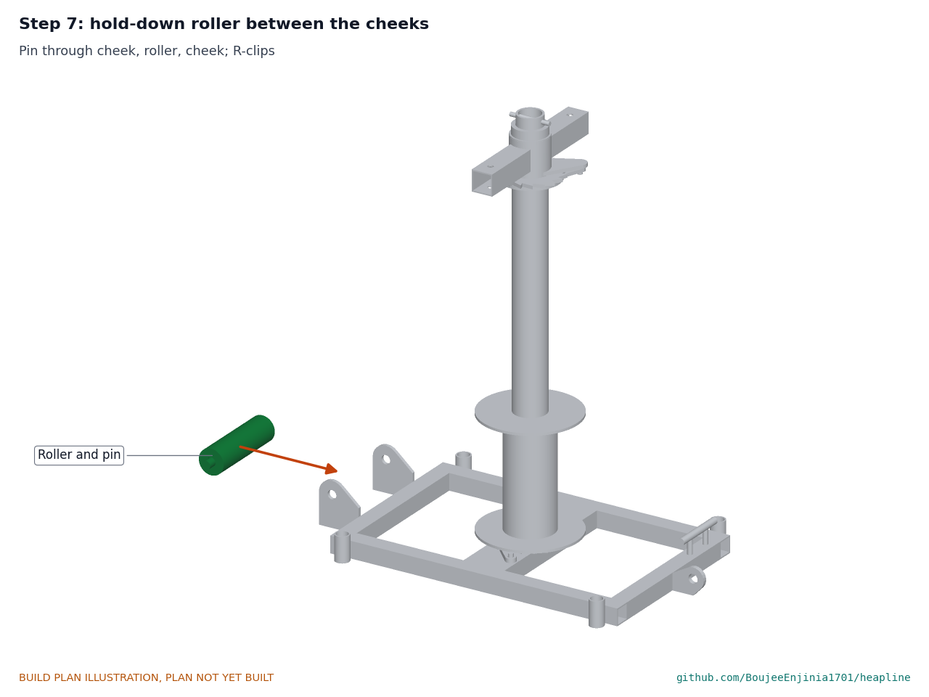
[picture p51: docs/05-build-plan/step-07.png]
Step 7


Hold the roller between the cheeks, push the 20 mm pin through cheek, roller and cheek, and R-clip both ends.

### Step 8: bars into the sockets

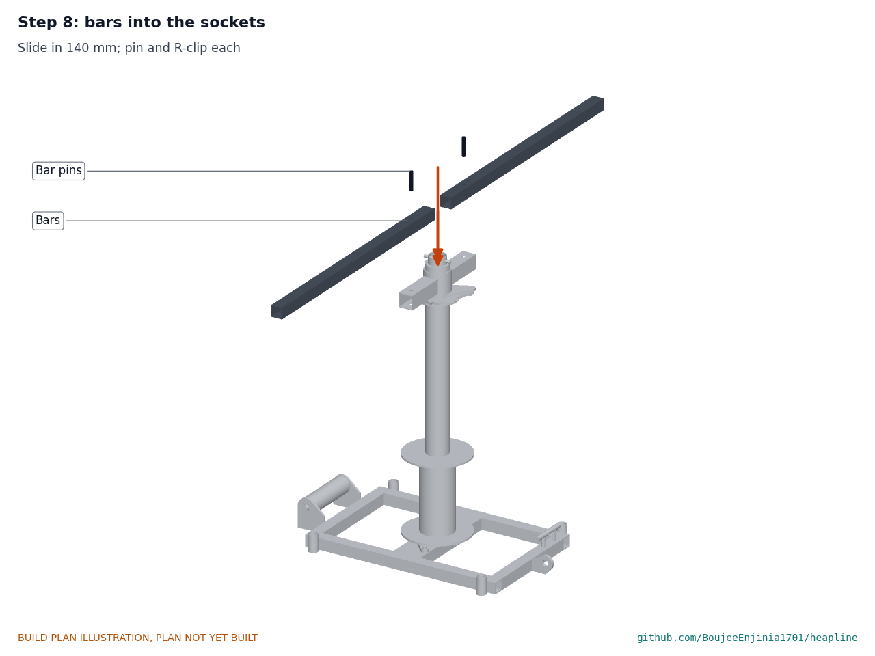
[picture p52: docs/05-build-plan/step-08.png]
Step 8


Slide each bar 140 into its socket and drop its pin through; R-clip. Pump the bars through a quarter turn and back: the drum turns one way only.

### Step 9: join the probe sections

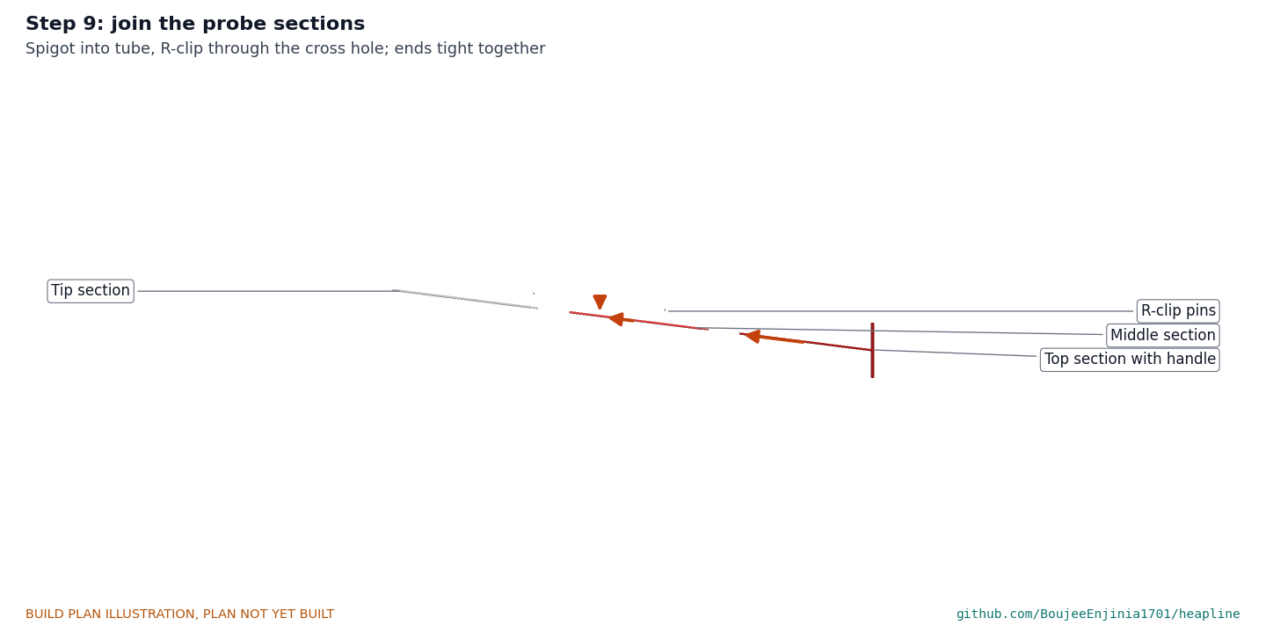
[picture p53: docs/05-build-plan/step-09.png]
Step 9


Push the middle section over the tip section's spigot until the tube ends meet and fit the R-clip; then the top section. Take them apart again for storage.

### Step 10: link two boards end to end

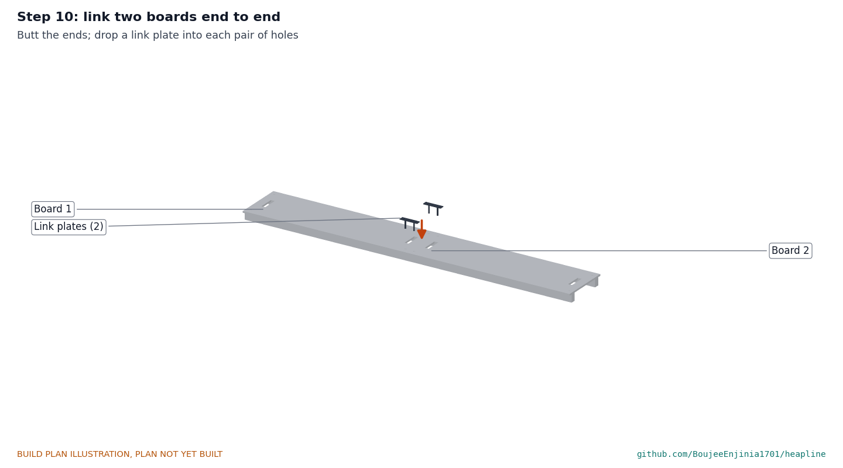
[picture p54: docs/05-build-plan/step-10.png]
Step 10


Butt two boards end to end and drop a link plate into each pair of holes.

### Step 11: pack the search crate and the capstan crate

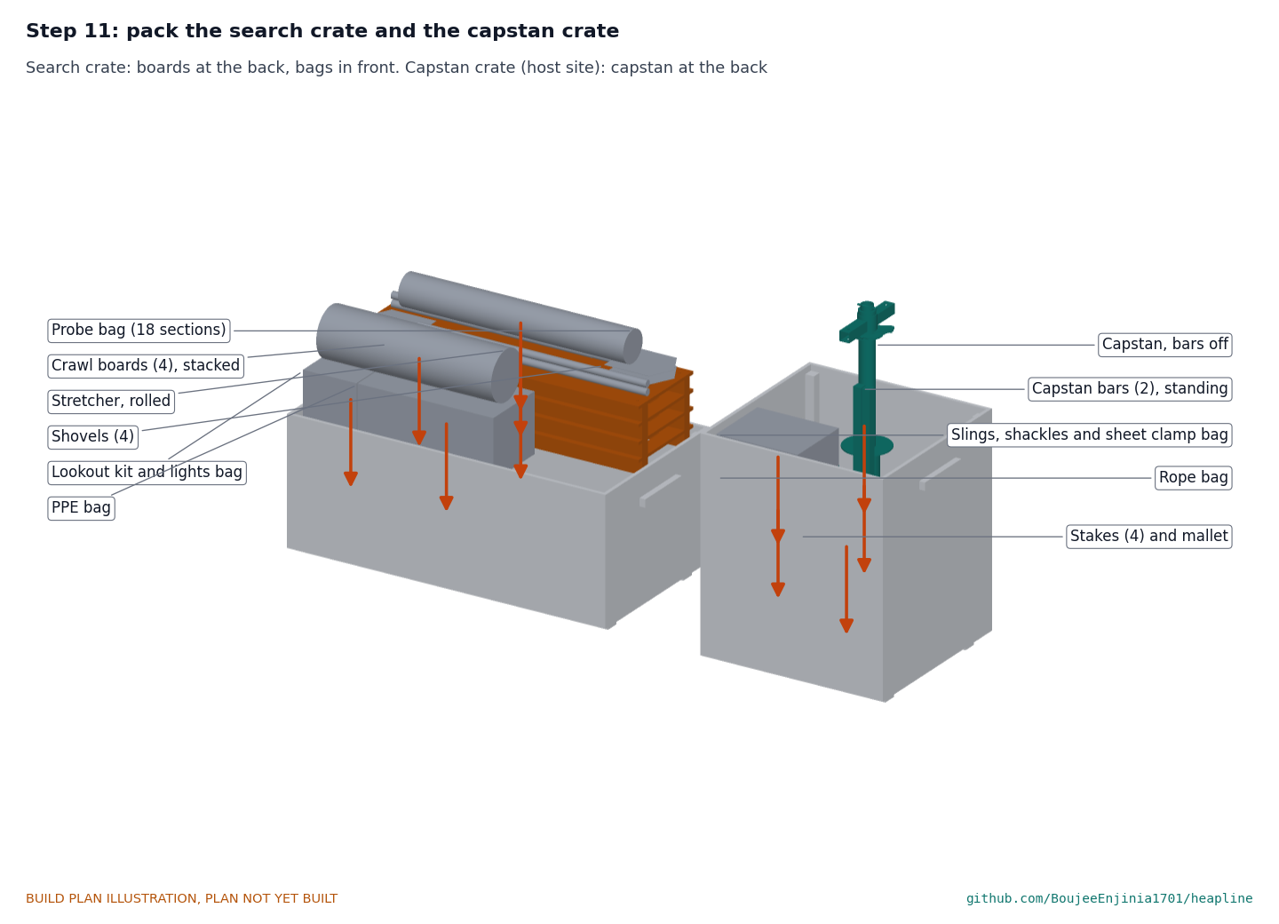
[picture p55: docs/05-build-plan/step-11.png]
Step 11


Search crate, at every site: the four boards flat at the back, then the shovels and the probe bag on them; the lookout and lamps bag and the PPE bag along the front, with the rolled stretcher on top of them. Capstan crate, at the host site only: the capstan upright at the back with its bars off and its stakes out; the rope bag with the slings and clamp bag on it, the stakes and hammer, and the two bars standing in the corner, along the front. Close each lid and lock it.

### Step 12: lookout posted, boards laid

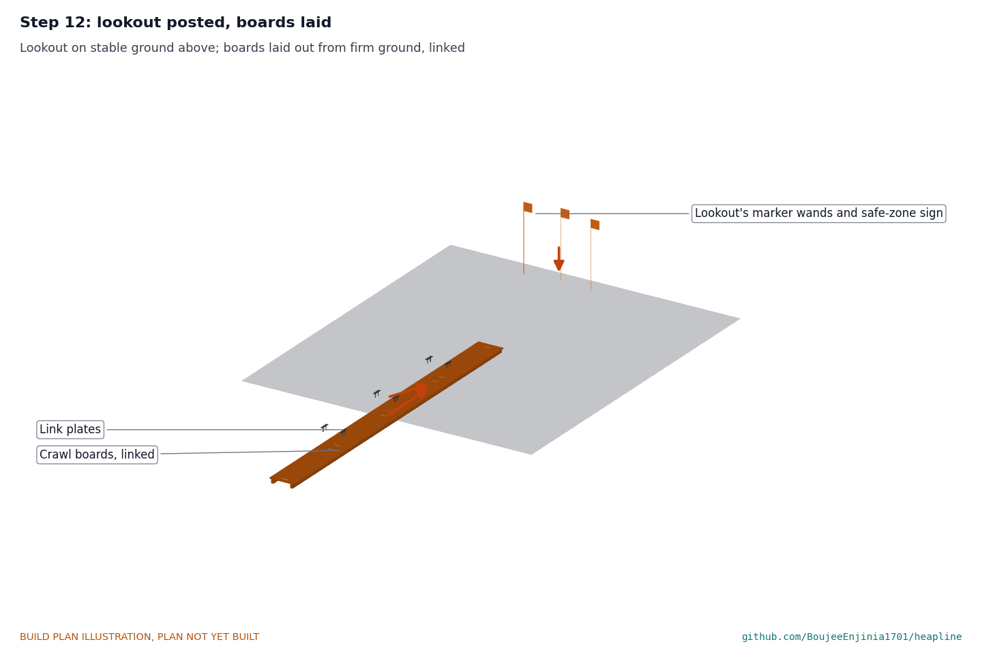
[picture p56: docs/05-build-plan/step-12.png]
Step 12


The kit goes out in two waves. Four people carry the search kit first, about 21.5 kg each; a second group of three brings the capstan set from the host site, about 21.7 kg each, and it is not needed until the probe line is working. On the practice heap, post the lookout first on firm ground to the side, with the whistle and the safe-zone sign. Lay the boards out from firm ground and link them.

### Step 13: probe line from the boards

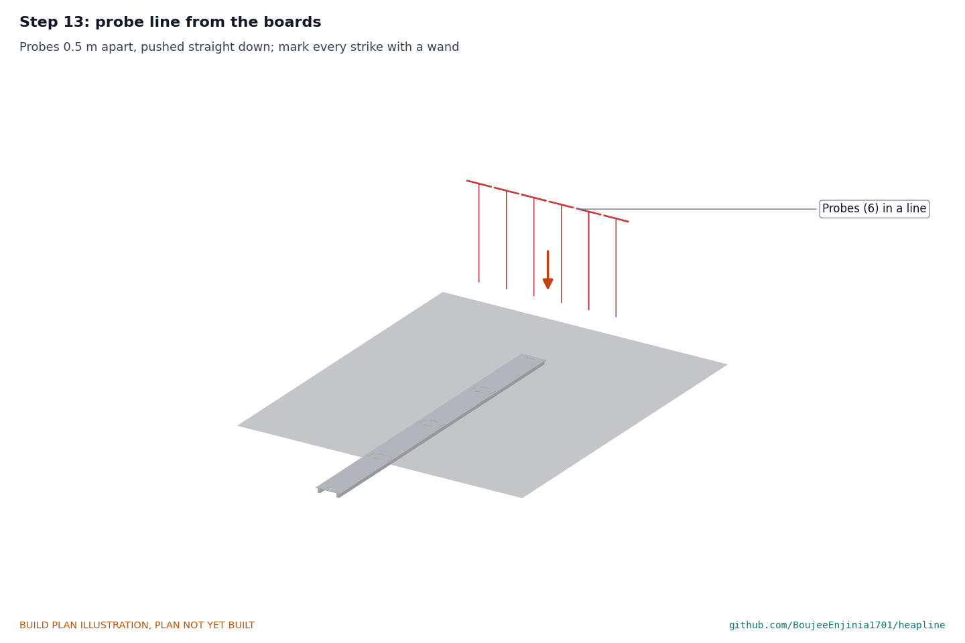
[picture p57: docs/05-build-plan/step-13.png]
Step 13


Join the probes and push them straight down in a line about 0.5 m apart from the boards. Mark every strike with a flagged wand.

### Step 14: set the capstan on firm ground

Step 14

Set the capstan on firm level ground to the side of the boards, its roller toward the load. Drive the four stakes. Sling the rear eye to a sound tree, a parked vehicle's recovery point or a structural column, low, so the sling runs level.

### Step 15: rig the clamp; stretcher alongside

Step 15

Clamp the sheet clamp on the sheeting and shackle the rope's eye to its lug. Lead the rope back under the roller, take four turns round the drum and hand the tail to the tailer. Lay the stretcher beside the boards. Clear the rope line (section 6) before the first stroke. When a casualty is moved, four people haul the stretcher whenever it crosses debris; two may haul it only along the boards.

## 5. First checks

These are listed here and recorded in a TRL 4 test report, not in this plan.

*Table 2. First checks.*

| Check | Requirement | How | Pass when |
| --- | --- | --- | --- |
| Deployment drill | R1 | Timed from a whistle 100 m from the shed | First probe in within 5 min |
| Capstan wave drill | R8 | Timed from the alarm, the three-person capstan wave walks from the host shed to a site about 500 m away | Capstan at the site within about 15 min (sets the 500 m sharing limit) |
| Probe reach | R2 | 18 mm tip probes pushed by one and by two people on a test heap of mixed waste, loose and compacted | Two people reach 2.5 m in compacted waste; record whether the sleeve friction is higher than assumed |
| Board sinkage | R3 | 100 kg on a board on loose fill; then across a 0.8 m gap | Sinkage under 50 mm; no cracking |
| Capstan pull | R4 | Pull through a load cell with four people | 5 kN reached |
| Shear pin release | R10 | Pull against a fixed stop through a load cell, slowly | Pin shears between 5.1 and 7.6 kN; a pawl holds the drum |
| Holding | R11 | At working pull, let go of the bars | Drum stops within one tooth |
| Proof load of capstan and sling | R10 | CalRig or a load cell, held 1 min at 8 kN, nobody in the rope line | No movement over 2 mm, no damage |
| Stretcher haul | R5 | 100 kg manikin over 30 m: four haulers on debris, two along the boards | Record force and time; each hauler within 200 N |
| Stop rule | R6 | Ask every drill participant after the drill | All six signals named |
| Storage | R7 | Inspect after 12 months in the crates | Everything usable |
| Weighing and carry | R8 | Weigh every carried item; time both waves | Each 25 kg or less; each carrier 25 kg or less in each wave |

## 6. Safety stops

Work stops at each of these points until what is listed is true.

1. **Before any drill.** The practice heap cannot slide: it is low, on flat ground, and nobody is in or under it. A lookout is posted and the stop rule has been read out. The fire service has been told about the drill.
2. **Before stepping onto debris.** A lookout is on stable ground to the side with a whistle; the safe zone is marked to the side of the slide path, never below it; everyone wears gloves and boots; nobody smokes.
3. **Before any rope is loaded.** The capstan stands on firm natural ground, not waste. The four stakes are in. The sling goes to a sound anchor (a tree at least 200 mm across at its base, a parked and braked vehicle's recovery point, or a structural column), runs level and is shackled to the rear eye. A 6 mm S275 shear pin is fitted, never a bolt or a harder pin. Both holding pawls are down on the teeth.
4. **Before each pull.** Nobody stands in the line of the rope, within 2 m of it, or between the load and the dig. The load is sheeting, timber or debris pulled sideways away from the dig; the capstan never lifts and never pulls on a person. The tailer stands behind the capstan, outside the bars' swing.
5. **Whenever hauling stops.** The tail is made fast on the cleat and the pawls are holding before anyone lets go.
6. **After a shear pin breaks.** Stop. Slack the rope by lifting the pawls one tooth at a time with the bars held. Find out why it broke; fit a new pin of the same 6 mm S275 bar from the tag chain.
7. **On any stop signal.** Everyone leaves the debris along the boards to the safe zone at once, whatever they are doing.
8. **At the end of each drill and at each monthly inspection.** Inspect the rope, splice, slings, shackles, pawls, pins, boards and probes; replace anything cut, cracked, bent or worn; check the lamp cells, the padlocks and that the PPE taken from the cooperative's stock is all there.

## 7. Tools, skills and workspace

- MIG welder (or a small stick welder with 2.5 mm electrodes) and a person who can weld 2 and 3 mm tube square; welding screen, gloves and mask.
- Angle grinder, metal saw, pillar drill with bits to 22 mm and a 61 mm hole saw; a lathe or a machine shop for the probe tips and the acetal bushes.
- Laser or plasma profile cutting for the ratchets and pawls, from a local cutter.
- Circular saw or table saw, jigsaw, drill and screwdriver for the plywood and the crate refit; clamps; exterior glue.
- Rivet tool for the stretcher; spanners for M12; R-clip pliers.
- A flat floor or welding table about 1.2 x 1.0 m; a floor 2 x 2 m for refitting the crates; two people for the drum, frame and crates.
- Rope work: the eye splice in double braid made by a rigger, or bought made.

## 8. Where the numbers come from

- `cad/src/model.py`: the parametric model, its constructability and packing checks, and the STEP and STL files in `cad/step` and `cad/stl`.
- `cad/drawings/HPL-DWG-001` and `HPL-DWG-002`: general arrangement of the capstan and the packed search and capstan crates; `HPL-DWG-101` to `HPL-DWG-116`: making sketches.
- `docs/04-calcs/01-sizing.md` and `docs/04-calcs/sizing.py` (HPL-CAL-001): forces, strengths, masses, times and costs.
- `bom/bom.csv`: parts, specifications and prices.
- `docs/decisions/0002-design-for-construction.md` (HPL-DDR-002): the changes in section 2; `docs/decisions/0003-requirement-decisions.md` (HPL-DDR-003): the probe tip, the crates, the shared capstan set and the drill-card rules.
- `cad/src/build_plan_media.py`: every picture in this plan.

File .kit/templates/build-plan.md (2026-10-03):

---
doc_id: PRJ-BLD-001
title: Project prototype build plan
project: Project name
doc_type: Build plan
version: "0.1"
status: Draft
date: YYYY-MM-DD
author: Amish Chadha
license: CERN-OHL-S-2.0
revisions:
  - version: "0.1"
    date: YYYY-MM-DD
    author: Amish Chadha
    change: First build plan; design made constructable
---

# Project prototype build plan

**Plan, not yet built.** How to build the first proof-of-concept prototype, component by component. Building and testing to it is TRL 4 work. Decisions still to be made are kept in the design decisions register (`docs/06-design-decisions.md`), not here.

## 1. What you are building

Every component, pulled apart and numbered in build order

One short paragraph: what the prototype is, how many components, which are made and which are bought, and the main ways they are made.

## 2. What changed to make it buildable

| Component | The concept had | The buildable design has | Why |
| --- | --- | --- | --- |

## 3. Making the components

### 3.1 Component name

Making sketch

**What it is and what it is made from.**

**How to make it.**

1. Mark out ...
2. Cut ...

**How it fits the parts next to it.**

Close-up of the joint

**Check before moving on.**

## 4. Putting it together

### Step 1: ...

Step 1

## 5. First checks

| Check | Requirement | How | Pass when |
| --- | --- | --- | --- |

## 6. Safety stops

## 7. Tools, skills and workspace

## 8. Where the numbers come from

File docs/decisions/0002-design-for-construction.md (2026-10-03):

---
doc_id: HPL-DDR-002
title: HeapLine design for construction
project: HeapLine
doc_type: Design decision record
version: "0.1"
status: Draft
date: '2026-10-03'
author: Amish Chadha
license: CERN-OHL-S-2.0
revisions:
- version: "0.1"
  date: '2026-10-03'
  author: Amish Chadha
  change: Constructability review and changes that make the design buildable, decided under Amish's pre-approvals of 2026-10-03
---

# 0002: Design for construction

- **Date:** 2026-10-03
- **Status:** accepted

## Context

STANDARDS section 18 asks for every part to be makeable by its stated process and to fit and fasten to its neighbours (Amish, 2026-09-30: "fix the design assumptions to match and be physically feasible"). The TRL 2 concept (HPL-PRC-001 v0.2, HPL-DDR-001) was reviewed part by part in `cad/src/model.py`: how each part is made, how it joins each neighbour, and build123d checks for parts that overlap, parts that do not touch what holds them, and contents that do not fit the site box. The checks now report no overlaps and no floating parts. Amish pre-approved every recommendation on 2026-10-03: "start with the first 14 repos from the list of 29 projects. I pre-approve the batch runs along with any recommendations you come up with. I also accept any cost overruns or variations from the assumed scope cost." and, for this batch, "Proceed with the remaining 15 scaffolds". No change alters what HeapLine does or its pitch; the safety-related changes all take the conservative side.

> **Safety:** Changes 3, 6, 7 and 8 carry the capstan's safety case (no tipping, overload limit, holding, nothing coming off the post). Change 11 keeps the probe tip blunt.

## Options considered

For each problem the simplest physically sound fix was chosen; the alternatives are noted in Table 1.

## Decision

*Table 1. Changes made for construction.*

| # | Part | Problem found | Change | Why |
| --- | --- | --- | --- | --- |
| 1 | Capstan base | The concept had a capstan "on a ground anchor" with no base | Frame 700 x 440 in 40 x 40 x 3 tube with a 100 x 40 x 4 centre member; 19.2 kg with the post | A base that carries the post, the roller, the eye and the stakes |
| 2 | Post | A post standing on a plate would have to carry 0.7 kN m at its foot through one weld | Post 60.3 x 5.0 passes through the centre member and is welded at the top and bottom faces | The two welds form a couple; 63 MPa in the tube |
| 3 | Rope lead | Rope leaving the drum 130 mm up while the sling pulls lower would tip the capstan; walkers or bar crews would step over a rope at knee height | A hold-down roller at the front takes the rope down to 38 mm above the ground, level with a rear anchor eye | No tipping moment; the rope lies along the ground |
| 4 | Drum | A drum turning on nothing | Barrel on two discs and a spindle up to bar height, turning on three acetal bushes on the fixed post, standing on an acetal thrust washer | Every turning part has a bearing surface |
| 5 | Head | Bars fixed to the drum mean walking round | A lever head turning on its own bush, with two radial sockets and a drive pawl on a 20-tooth drive ratchet | Pumping through a quarter turn; nobody moves their feet |
| 6 | Shear pin | Not placed | 6 mm pin through the drum's top flange and the drive ratchet on a 60 mm radius; the drive ratchet is otherwise free on the post | Only the pin passes the drive (R10) |
| 7 | Pawls | Pawl bodies first drawn clashed with the teeth behind their noses | Noses 0.12 of a tooth past the face; pivots along the tangent lifted 30 degrees; checked clear by intersection | Each pawl clears the teeth it rides over (R11) |
| 8 | Keeper | Nothing held the head and drum on the post when it is carried or tipped | Collar and 10 mm cross pin on the post top | Parts cannot slide off |
| 9 | Stakes | No way to stop the frame turning against the pawl reaction | Four stake tubes at the corners; 25 mm stakes with welded heads | Each stake rests on its tube |
| 10 | Tail | Nowhere to make the tail fast | Horn cleat on the rear member | Tail made fast whenever hauling stops |
| 11 | Probes | Joint and tip not defined | Three 1 m sections of 16 x 2.0 tube on 11.5 mm spigots with 5 mm R-clips; tube ends bear on each other; 22 mm tip with a 3 mm rounded point | Push goes through the tube, not the pin; tip 3 mm wider than the tube each side cuts friction |
| 12 | Crawl boards | No way to join boards; deck alone too flexible over a void | Two 45 x 70 battens 30 mm in from the edges; four 13 mm holes; link plates with two 12 mm pins drop across each joint | Boards stay in line; bridges a 0.8 m void at 4.0 MPa |
| 13 | Site box | The assembled capstan (995 mm tall) and the 1.5 m boards did not fit the concept box | Box enlarged to 1700 x 1020 x 1060 mm on skids, with corner battens and a lid skirt over a seal; a packing layout checked clear of every wall and item | Everything packs; nothing has to be assembled at the slide except the bars |
| 14 | Sheet clamp | The capstan had no way to grip plastic sheeting | A bolted two-bar clamp with a shackle lug | Holds about 6 kN, below the pin's release |
| 15 | Stretcher | Handles and straps not defined | Twelve hand slots, three riveted straps with cam buckles, a head haul strap | Fixings |

## Consequences

- `cad/src/model.py` holds the constructable design; STEP and STL, HPL-DWG-001 and 002 (Rev P2), the concept media and the build plan pictures are regenerated from it.
- HPL-CAL-001 is written on it; the parts cost is USD 1,599, USD 201 under the value-engineering target.
- The site box is heavier (104 kg) but never leaves the shed.
- `design_state: constructable` is set in `project.yaml`.

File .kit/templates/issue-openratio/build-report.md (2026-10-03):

---
name: Build report
about: Tell us what happened when you built, printed or tested part of this design
title: "Build report: "
labels: build-report
---

This is a research and educational prototype, not a medical device. It is a TRL 3 concept and is not released for fabrication. If you build any part of it, you do so at your own risk. Reports help everyone.

**What you built** (part, sub-assembly or test)

**Materials, tools and settings**

**What worked**

**What did not work, with photos or measurements if you have them**

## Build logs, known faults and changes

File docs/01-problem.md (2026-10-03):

---
doc_id: HPL-PRB-001
title: HeapLine problem statement
project: HeapLine
doc_type: Problem statement
version: "0.2"
status: Draft
date: '2026-10-03'
author: Amish Chadha
license: CERN-OHL-S-2.0
revisions:
- version: "0.1"
  date: '2026-09-30'
  author: Amish Chadha
  change: Initial scaffold
- version: "0.2"
  date: '2026-10-03'
  author: Amish Chadha
  change: TRL 2 and 3 update; first co-design candidate named (HPL-DDR-001); open questions answered or carried to the first trials; safety note
---

# HeapLine problem statement

In the first minutes after a dumpsite slide, the only people who can reach buried victims are those already on site. Today they search without tools, a plan or any protection from a second slide.

## The problem

The death tolls at Koshe and Kiteezi came from slides onto homes and working areas where hundreds of people spend their days ([IDS, 2017](https://www.ids.ac.uk/opinions/recognise-informal-waste-pickers-to-avoid-future-disasters-like-koshe/); [Wikipedia](https://en.wikipedia.org/wiki/Kiteezi_Landfill)). Formal rescue has to travel to the site, and at Kiteezi coverage described the effort as rudimentary ([The Independent, Uganda, 2024](https://www.independent.co.ug/cover-story-lets-not-waste-kiteezi-garbage-tragedy/)). Evidence from snow avalanches, the closest well-studied analogue, shows why speed matters: in Swiss data on 422 buried skiers, 92 % survived if dug out within 15 minutes but only 30 % after 35 minutes ([Wikipedia, avalanche rescue](https://en.wikipedia.org/wiki/Avalanche_rescue)). Waste is not snow, but the lesson that the people on the spot must search at once carries over.

The long-term answer is to engineer or close dumpsites. At Koshe, rehabilitation after 2017 added compacted roads, gas venting pipes and graded slopes, and pickers report no fear of slides ([UN-Habitat, 2019](https://unhabitat.org/news/05-jul-2019/after-the-tragic-landslide-that-killed-116-koshe-landfill-in-addis-ababa-is-safer)). That work takes years and money that many sites do not have. Avalanche companion kits (probe, shovel and beacon) are designed for snow and for people who carry them on their bodies ([Wikipedia](https://en.wikipedia.org/wiki/Avalanche_rescue)). Nothing packages a site-kept kit and drill for waste pickers.

## Users and context

| User | Need | Context |
| --- | --- | --- |
| Waste pickers and their cooperatives | Search and dig for buried colleagues and neighbours in the first minutes, without being buried themselves | Open dumps and uncontrolled landfills, often with homes at the toe |
| Neighbours living beside the dump | Join a search that has a lookout, a plan and a clear point to stop | Informal housing downslope of the waste |
| Site operators and municipal staff | A low-cost emergency measure they can stock and inspect | Sites awaiting closure or rehabilitation |
| Fire, police and Red Cross responders | Arrive to a search that is organised, with burial points marked | Handover from community search to formal rescue |

## Operating environment

- Loose, wet, mixed waste with voids, plastic sheeting, sharp objects and debris flows; ground can keep moving after the first slide.
- Landfill gas at some sites, which is why rehabilitated sites add gas venting ([UN-Habitat, 2019](https://unhabitat.org/news/05-jul-2019/after-the-tragic-landslide-that-killed-116-koshe-landfill-in-addis-ababa-is-safer)).
- Heavy rain preceded the Kiteezi failure ([Eos Landslide Blog, 2024](https://eos.org/thelandslideblog/kiteezi-1)), so searches may happen in rain and mud.
- Kit stored for months in a shed in heat, damp and dust; must still work on the day.
- No power at the scene; lighting may be needed at night.

## Constraints

- Value-engineering target of USD 1,800 for the prototype (a hypothetical control target, not a spending limit).
- Parts cost target under USD 400 per site kit (target).
- Carried to the slide by four people or fewer; no single item over 25 kg (55 lb) (target).
- Made from common steel tube, timber or plastic board, rope and tarpaulin; repairable locally.
- Kit and drill must include a lookout and a written stop rule.
- Open hardware under CERN-OHL-S-2.0; drawings published with dates early (IP screen).

## Out of scope

- Slope stability monitoring or early warning (a separate problem).
- Engineering, rehabilitation or closure of the dumpsite.
- Heavy plant such as excavators.
- Medical treatment beyond moving casualties to a pickup point.

## Prior work

| Prior work | What it does | Gap for these users | Source |
| --- | --- | --- | --- |
| Avalanche companion rescue (probe, shovel, beacon) | Survivors search at once with probes and shovels instead of waiting for help | Carried on the body and designed for snow, not a site-kept kit for mixed waste | [link](https://en.wikipedia.org/wiki/Avalanche_rescue) |
| Koshe rehabilitation using the Fukuoka method (UN-Habitat) | Compacted roads, gas venting and graded slopes that reduce slide risk | Prevention that takes years and funding; no first-minute rescue capability | [link](https://unhabitat.org/news/05-jul-2019/after-the-tragic-landslide-that-killed-116-koshe-landfill-in-addis-ababa-is-safer) |
| Formal response at Kiteezi, 2024 | Government and agency search and recovery after the collapse | Described as rudimentary; arrives after the first minutes | [link](https://www.independent.co.ug/cover-story-lets-not-waste-kiteezi-garbage-tragedy/) |

## Co-design

A waste pickers' cooperative or association at an active dumpsite, working with the local fire and rescue service or Red Cross branch, so the kit contents and the stop rule are shaped by the people who will use them and agreed with those who take over the search.

The first candidate to approach is the Uganda Red Cross Society in Kampala, together with the waste pickers who work at Kiteezi (HPL-DDR-001, item 11). This is a candidate to approach, not an agreement.

> **Safety:** A second slide can bury the searchers. HeapLine is published as an open engineering reference, not certified rescue equipment. Every search has a lookout and a stop rule, the fire service and emergency services are called at once, and nobody smokes or uses a naked flame near the debris.

## Open questions

Answered for the design at TRL 3 (HPL-DDR-001):

- **Stop rule.** Six signals, any one of which sends everyone to the marked safe zone at once: the lookout's long whistle; new cracks, bulging or movement on the slope above; water or mud flowing from the debris; rain getting heavier; a gas smell, smoke or hissing; or a formal responder's order. It is printed on the lid and on pocket cards.
- **Gas detector.** Not in the base kit: a detector that is not bump-tested and calibrated can give false comfort. The rule is no flames or smoking and stop on any sign of gas. A partner who will maintain a detector monthly would allow one to be added.
- **Ownership.** The cooperative or, where there is none, the site operator owns the kit and keeps a monthly inspection log.

Carried to the first trials with the co-design partner (TRL 4):

- How deep are people typically buried in dumpsite slides, and how far can probes be pushed in real slide debris? HPL-CAL-001 shows the answer depends strongly on how compact the debris is.
- How should the kit be introduced so it is not read as accepting unsafe dumps?

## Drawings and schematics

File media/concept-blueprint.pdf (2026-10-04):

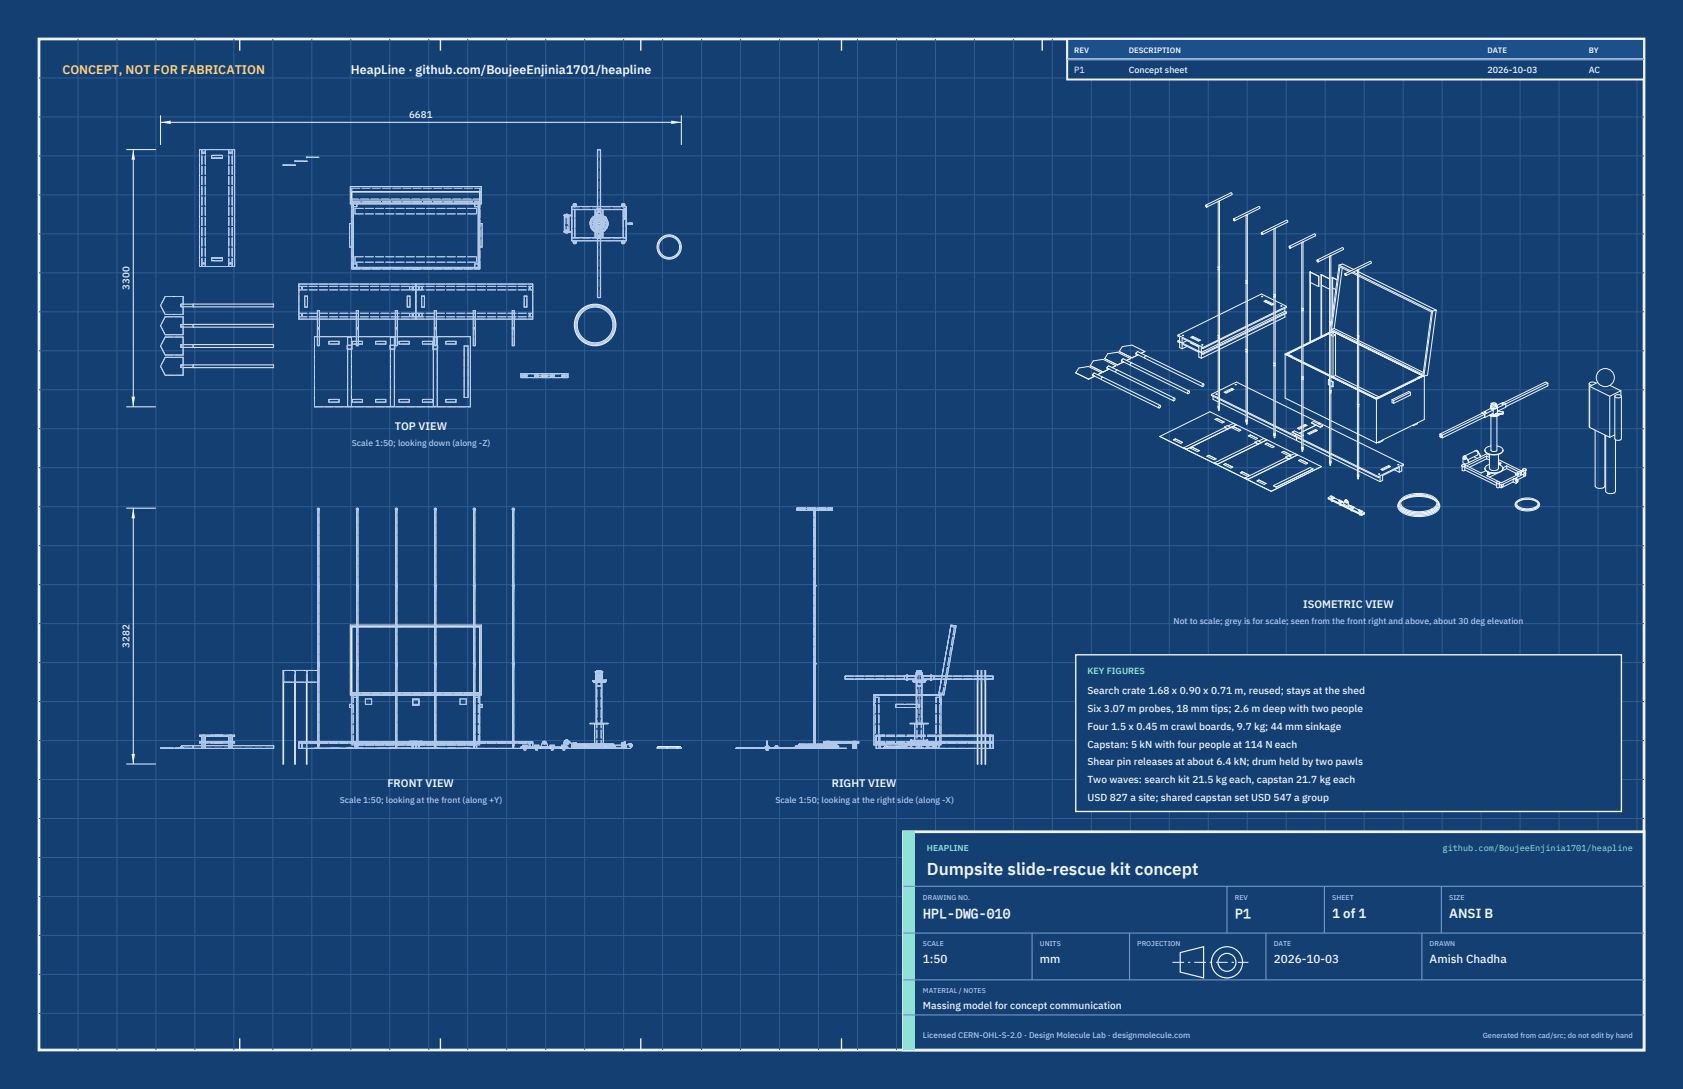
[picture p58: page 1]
CONCEPT, NOT FOR FABRICATION; HeapLine · github.com/BoujeeEnjinia1701/heapline; FRONT VIEW; TOP VIEW; RIGHT VIEW; ISOMETRIC VIEW; REV; DESCRIPTION; DATE; Concept sheet; HEAPLINE; github.com/BoujeeEnjinia1701/heapline; DRAWING NO. HPL-DWG-010; REV P1; SHEET 1 of 1; SIZE ANSI B; SCALE 1:50; UNITS mm; PROJECTION; DRAWN Amish Chadha; Licensed CERN-OHL-S-2.0 · Design Molecule Lab · designmolecule.com; Generated from cad/src; do not edit by hand

Scale 1:50; looking down (along -Z)

Not to scale; grey is for scale; seen from the front right and above, about 30 deg elevation

KEY FIGURES
Search crate 1.68 x 0.90 x 0.71 m, reused; stays at the shed
Six 3.07 m probes, 18 mm tips; 2.6 m deep with two people
Four 1.5 x 0.45 m crawl boards, 9.7 kg; 44 mm sinkage
Capstan: 5 kN with four people at 114 N each
Shear pin releases at about 6.4 kN; drum held by two pawls
Two waves: search kit 21.5 kg each, capstan 21.7 kg each
USD 827 a site; shared capstan set USD 547 a group

Scale 1:50; looking at the front (along +Y)

Scale 1:50; looking at the right side (along -X)

Dumpsite slide-rescue kit concept

MATERIAL / NOTES
Massing model for concept communication

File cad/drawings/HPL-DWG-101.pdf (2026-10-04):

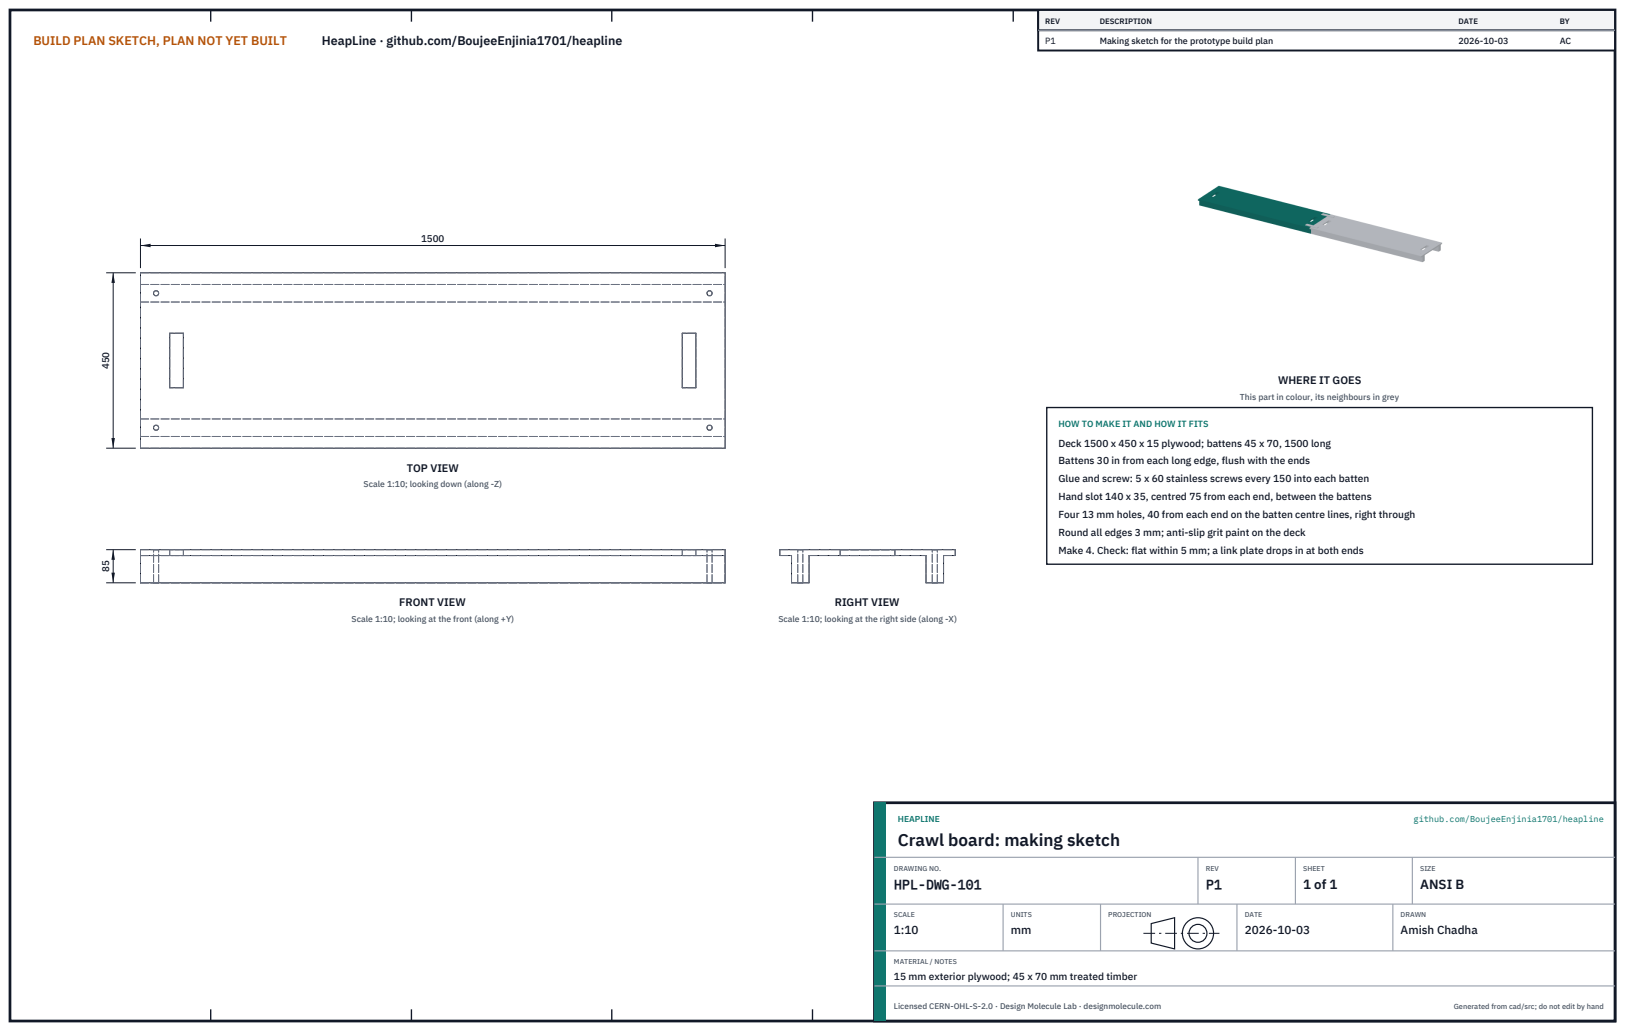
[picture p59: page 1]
BUILD PLAN SKETCH, PLAN NOT YET BUILT; HeapLine · github.com/BoujeeEnjinia1701/heapline; FRONT VIEW; TOP VIEW; RIGHT VIEW; REV; DESCRIPTION; DATE; Making sketch for the prototype build plan; HEAPLINE; github.com/BoujeeEnjinia1701/heapline; DRAWING NO. HPL-DWG-101; REV P1; SHEET 1 of 1; SIZE ANSI B; SCALE 1:10; UNITS mm; PROJECTION; DRAWN Amish Chadha; Licensed CERN-OHL-S-2.0 · Design Molecule Lab · designmolecule.com; Generated from cad/src; do not edit by hand

WHERE IT GOES

This part in colour, its neighbours in grey

HOW TO MAKE IT AND HOW IT FITS
Deck 1500 x 450 x 15 plywood; battens 45 x 70, 1500 long
Battens 30 in from each long edge, flush with the ends
Glue and screw: 5 x 60 stainless screws every 150 into each batten
Hand slot 140 x 35, centred 75 from each end, between the battens
Four 13 mm holes, 40 from each end on the batten centre lines, right through
Round all edges 3 mm; anti-slip grit paint on the deck
Make 4. Check: flat within 5 mm; a link plate drops in at both ends

Scale 1:10; looking down (along -Z)

Scale 1:10; looking at the front (along +Y)

Scale 1:10; looking at the right side (along -X)

Crawl board: making sketch

MATERIAL / NOTES
15 mm exterior plywood; 45 x 70 mm treated timber

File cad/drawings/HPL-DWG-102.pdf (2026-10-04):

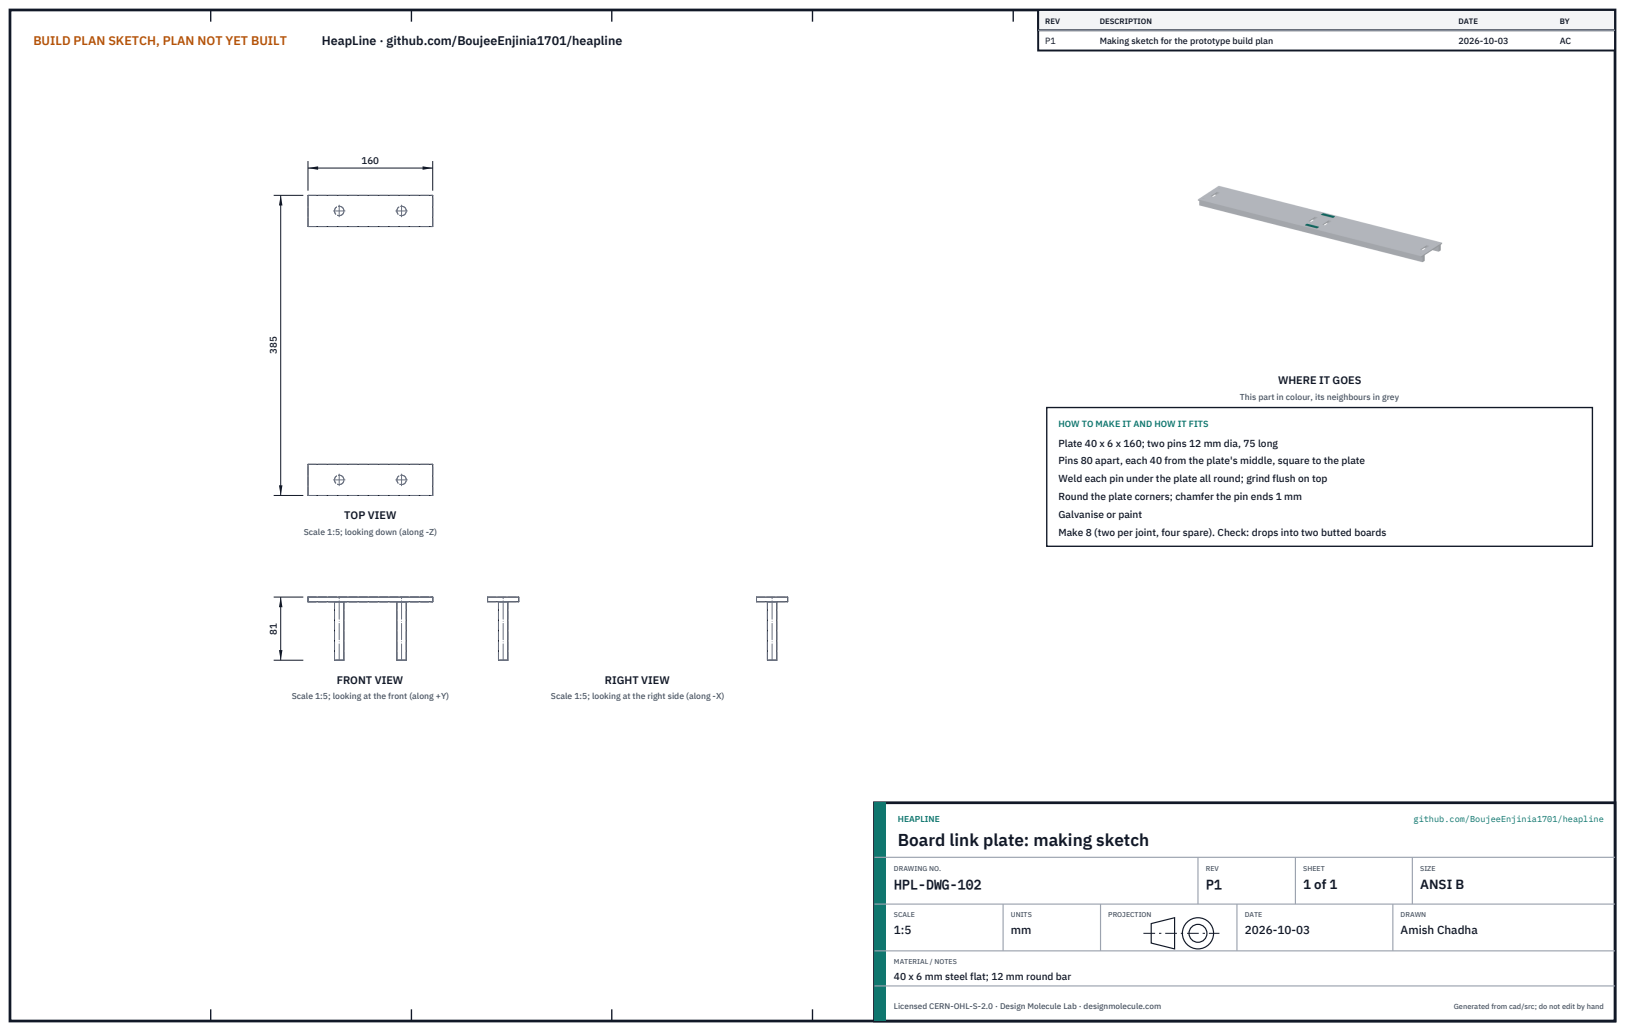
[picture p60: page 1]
BUILD PLAN SKETCH, PLAN NOT YET BUILT; HeapLine · github.com/BoujeeEnjinia1701/heapline; FRONT VIEW; TOP VIEW; RIGHT VIEW; REV; DESCRIPTION; DATE; Making sketch for the prototype build plan; HEAPLINE; github.com/BoujeeEnjinia1701/heapline; DRAWING NO. HPL-DWG-102; REV P1; SHEET 1 of 1; SIZE ANSI B; SCALE 1:5; UNITS mm; PROJECTION; DRAWN Amish Chadha; Licensed CERN-OHL-S-2.0 · Design Molecule Lab · designmolecule.com; Generated from cad/src; do not edit by hand

WHERE IT GOES

This part in colour, its neighbours in grey

HOW TO MAKE IT AND HOW IT FITS
Plate 40 x 6 x 160; two pins 12 mm dia, 75 long
Pins 80 apart, each 40 from the plate's middle, square to the plate
Weld each pin under the plate all round; grind flush on top
Round the plate corners; chamfer the pin ends 1 mm
Galvanise or paint
Make 8 (two per joint, four spare). Check: drops into two butted boards

Scale 1:5; looking down (along -Z)

Scale 1:5; looking at the front (along +Y)

Scale 1:5; looking at the right side (along -X)

Board link plate: making sketch

MATERIAL / NOTES
40 x 6 mm steel flat; 12 mm round bar

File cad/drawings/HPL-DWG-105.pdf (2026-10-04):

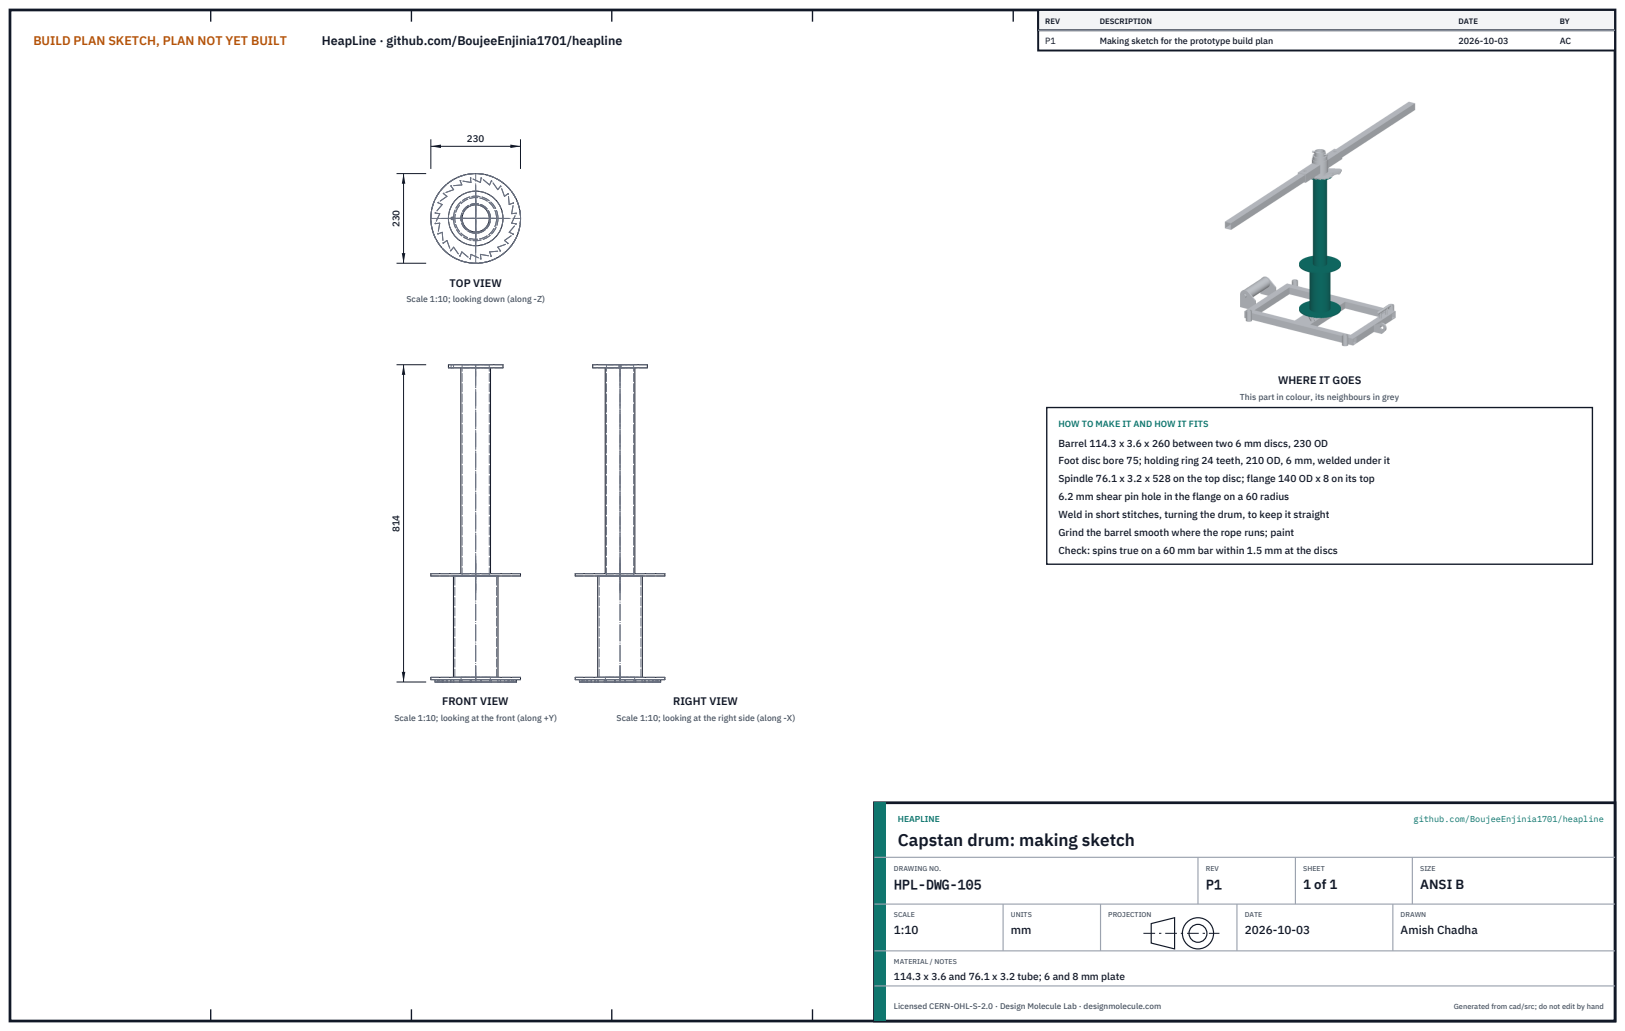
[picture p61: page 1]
BUILD PLAN SKETCH, PLAN NOT YET BUILT; HeapLine · github.com/BoujeeEnjinia1701/heapline; FRONT VIEW; TOP VIEW; RIGHT VIEW; REV; DESCRIPTION; DATE; Making sketch for the prototype build plan; HEAPLINE; github.com/BoujeeEnjinia1701/heapline; DRAWING NO. HPL-DWG-105; REV P1; SHEET 1 of 1; SIZE ANSI B; SCALE 1:10; UNITS mm; PROJECTION; DRAWN Amish Chadha; Licensed CERN-OHL-S-2.0 · Design Molecule Lab · designmolecule.com; Generated from cad/src; do not edit by hand

Scale 1:10; looking down (along -Z)

WHERE IT GOES

This part in colour, its neighbours in grey

HOW TO MAKE IT AND HOW IT FITS
Barrel 114.3 x 3.6 x 260 between two 6 mm discs, 230 OD
Foot disc bore 75; holding ring 24 teeth, 210 OD, 6 mm, welded under it
Spindle 76.1 x 3.2 x 528 on the top disc; flange 140 OD x 8 on its top
6.2 mm shear pin hole in the flange on a 60 radius
Weld in short stitches, turning the drum, to keep it straight
Grind the barrel smooth where the rope runs; paint
Check: spins true on a 60 mm bar within 1.5 mm at the discs

Scale 1:10; looking at the front (along +Y)

Scale 1:10; looking at the right side (along -X)

Capstan drum: making sketch

MATERIAL / NOTES
114.3 x 3.6 and 76.1 x 3.2 tube; 6 and 8 mm plate

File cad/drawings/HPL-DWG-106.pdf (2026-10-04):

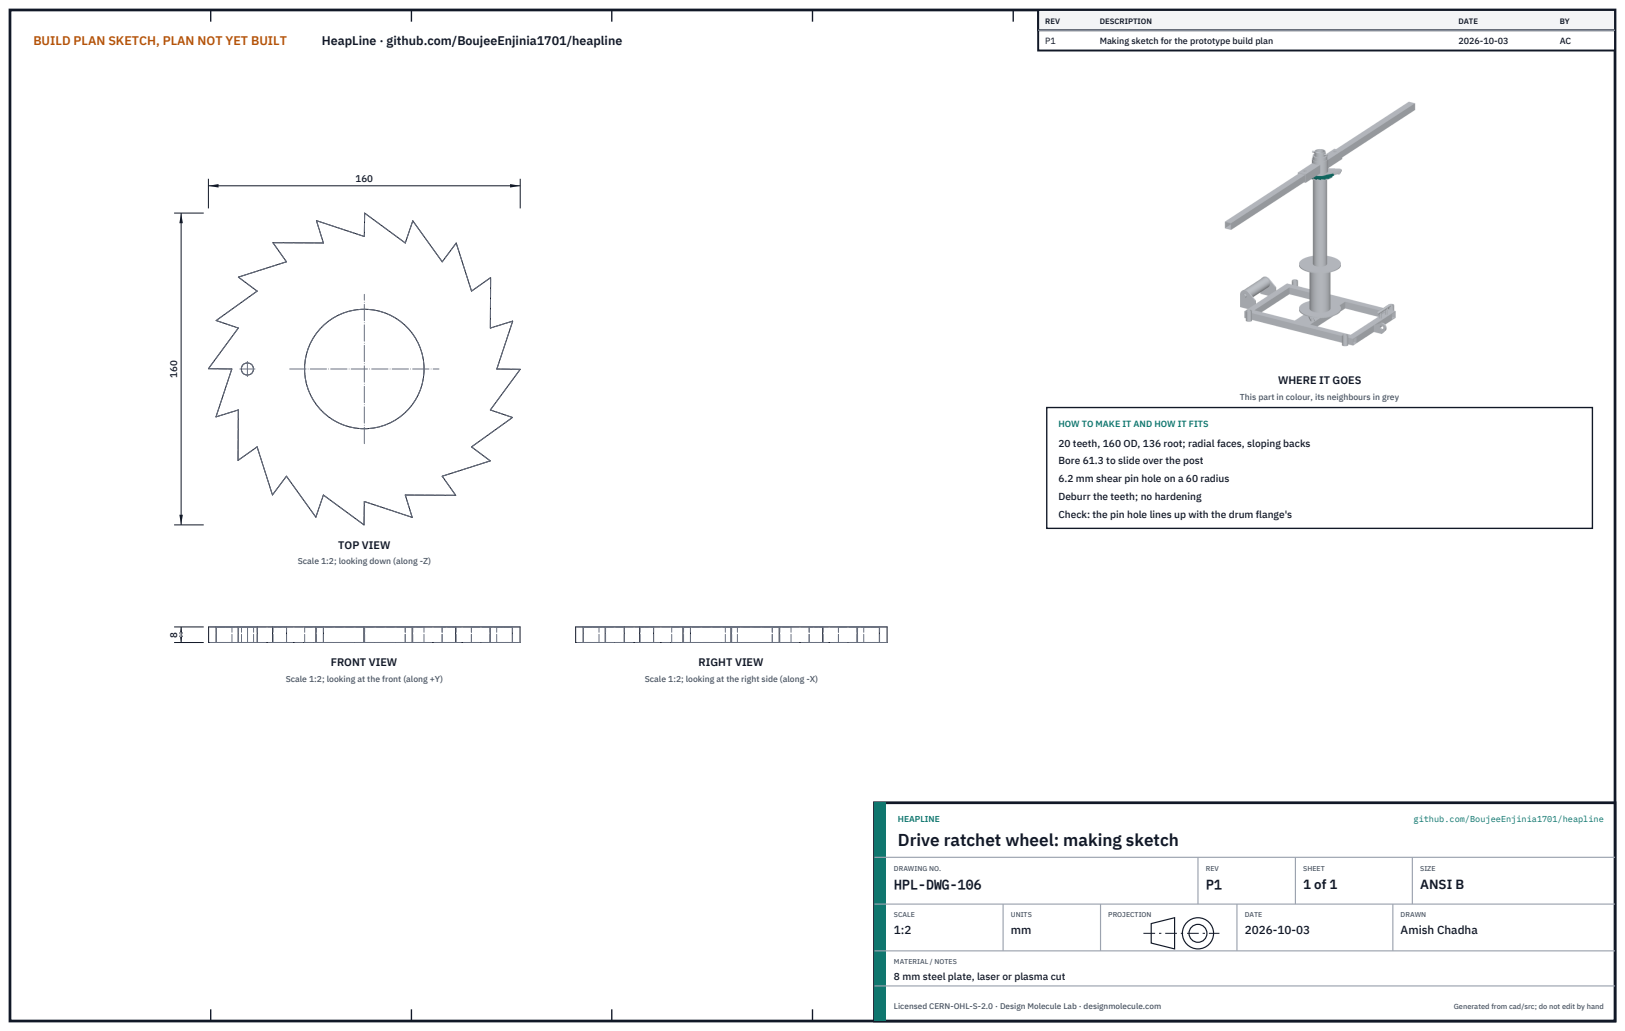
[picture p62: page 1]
BUILD PLAN SKETCH, PLAN NOT YET BUILT; HeapLine · github.com/BoujeeEnjinia1701/heapline; FRONT VIEW; TOP VIEW; RIGHT VIEW; REV; DESCRIPTION; DATE; Making sketch for the prototype build plan; HEAPLINE; github.com/BoujeeEnjinia1701/heapline; DRAWING NO. HPL-DWG-106; REV P1; SHEET 1 of 1; SIZE ANSI B; SCALE 1:2; UNITS mm; PROJECTION; DRAWN Amish Chadha; Licensed CERN-OHL-S-2.0 · Design Molecule Lab · designmolecule.com; Generated from cad/src; do not edit by hand

WHERE IT GOES

This part in colour, its neighbours in grey

HOW TO MAKE IT AND HOW IT FITS
20 teeth, 160 OD, 136 root; radial faces, sloping backs
Bore 61.3 to slide over the post
6.2 mm shear pin hole on a 60 radius
Deburr the teeth; no hardening
Check: the pin hole lines up with the drum flange's

Scale 1:2; looking down (along -Z)

Scale 1:2; looking at the front (along +Y)

Scale 1:2; looking at the right side (along -X)

Drive ratchet wheel: making sketch

MATERIAL / NOTES
8 mm steel plate, laser or plasma cut

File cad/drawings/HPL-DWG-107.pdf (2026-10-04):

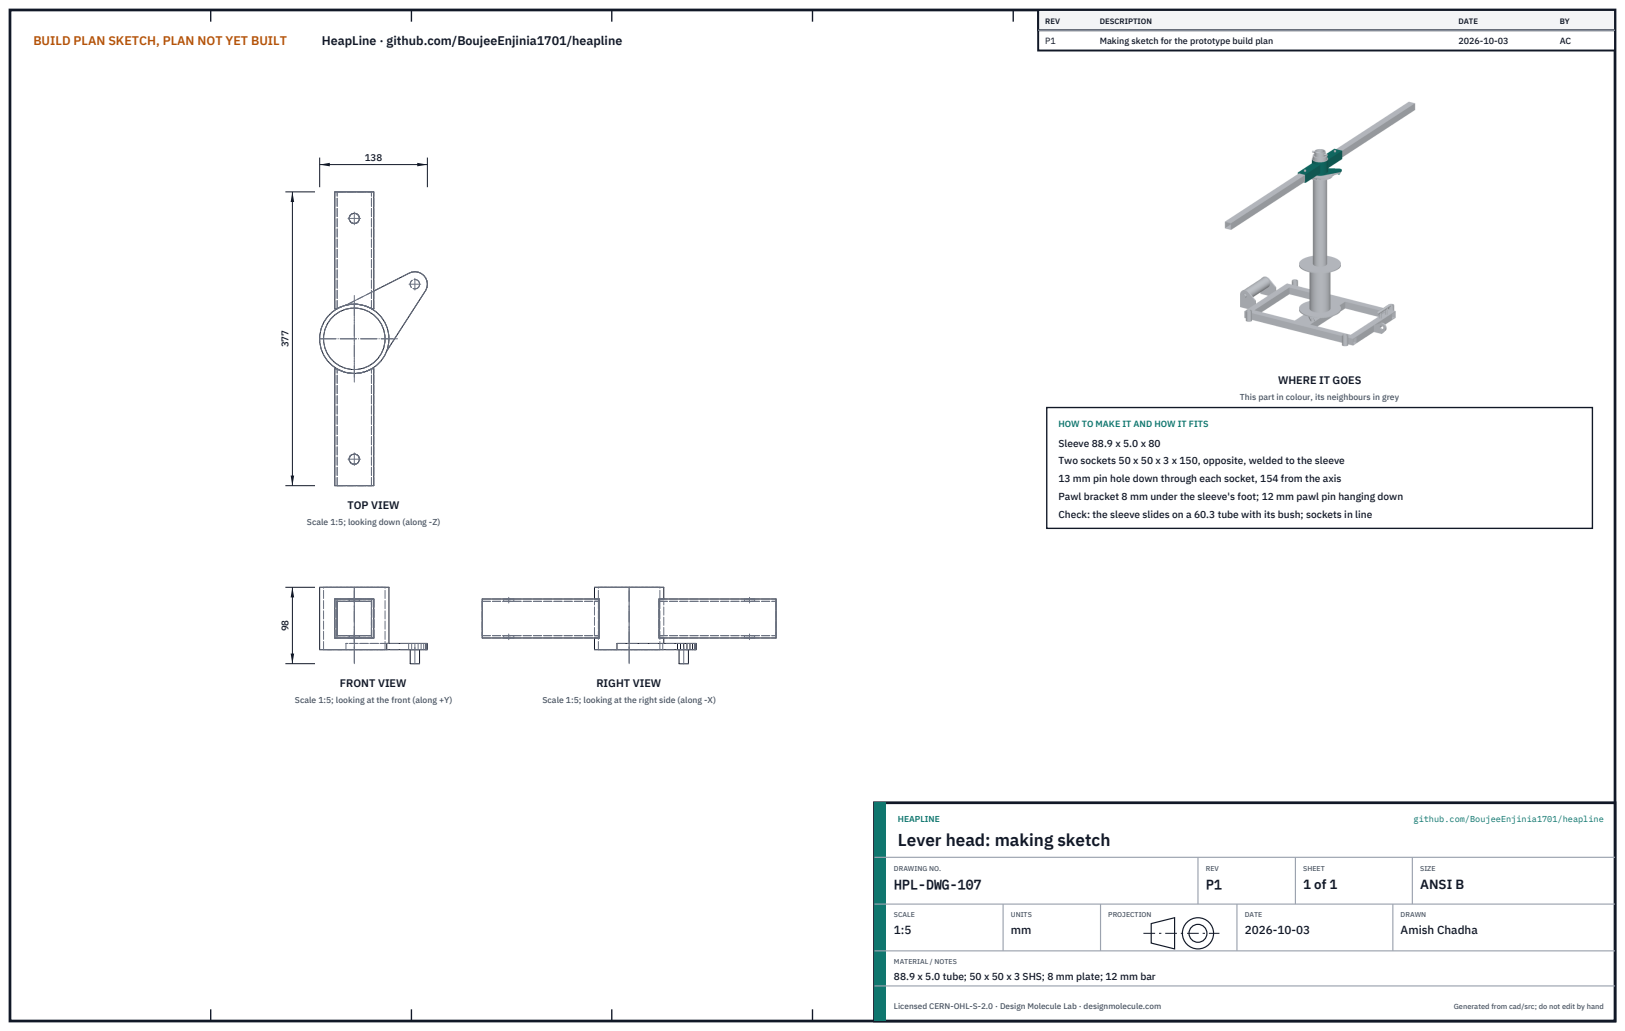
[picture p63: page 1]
BUILD PLAN SKETCH, PLAN NOT YET BUILT; HeapLine · github.com/BoujeeEnjinia1701/heapline; FRONT VIEW; TOP VIEW; RIGHT VIEW; REV; DESCRIPTION; DATE; Making sketch for the prototype build plan; HEAPLINE; github.com/BoujeeEnjinia1701/heapline; DRAWING NO. HPL-DWG-107; REV P1; SHEET 1 of 1; SIZE ANSI B; SCALE 1:5; UNITS mm; PROJECTION; DRAWN Amish Chadha; Licensed CERN-OHL-S-2.0 · Design Molecule Lab · designmolecule.com; Generated from cad/src; do not edit by hand

WHERE IT GOES

This part in colour, its neighbours in grey

HOW TO MAKE IT AND HOW IT FITS
Sleeve 88.9 x 5.0 x 80
Two sockets 50 x 50 x 3 x 150, opposite, welded to the sleeve
13 mm pin hole down through each socket, 154 from the axis
Pawl bracket 8 mm under the sleeve's foot; 12 mm pawl pin hanging down
Check: the sleeve slides on a 60.3 tube with its bush; sockets in line

Scale 1:5; looking down (along -Z)

Scale 1:5; looking at the front (along +Y)

Scale 1:5; looking at the right side (along -X)

Lever head: making sketch

MATERIAL / NOTES
88.9 x 5.0 tube; 50 x 50 x 3 SHS; 8 mm plate; 12 mm bar

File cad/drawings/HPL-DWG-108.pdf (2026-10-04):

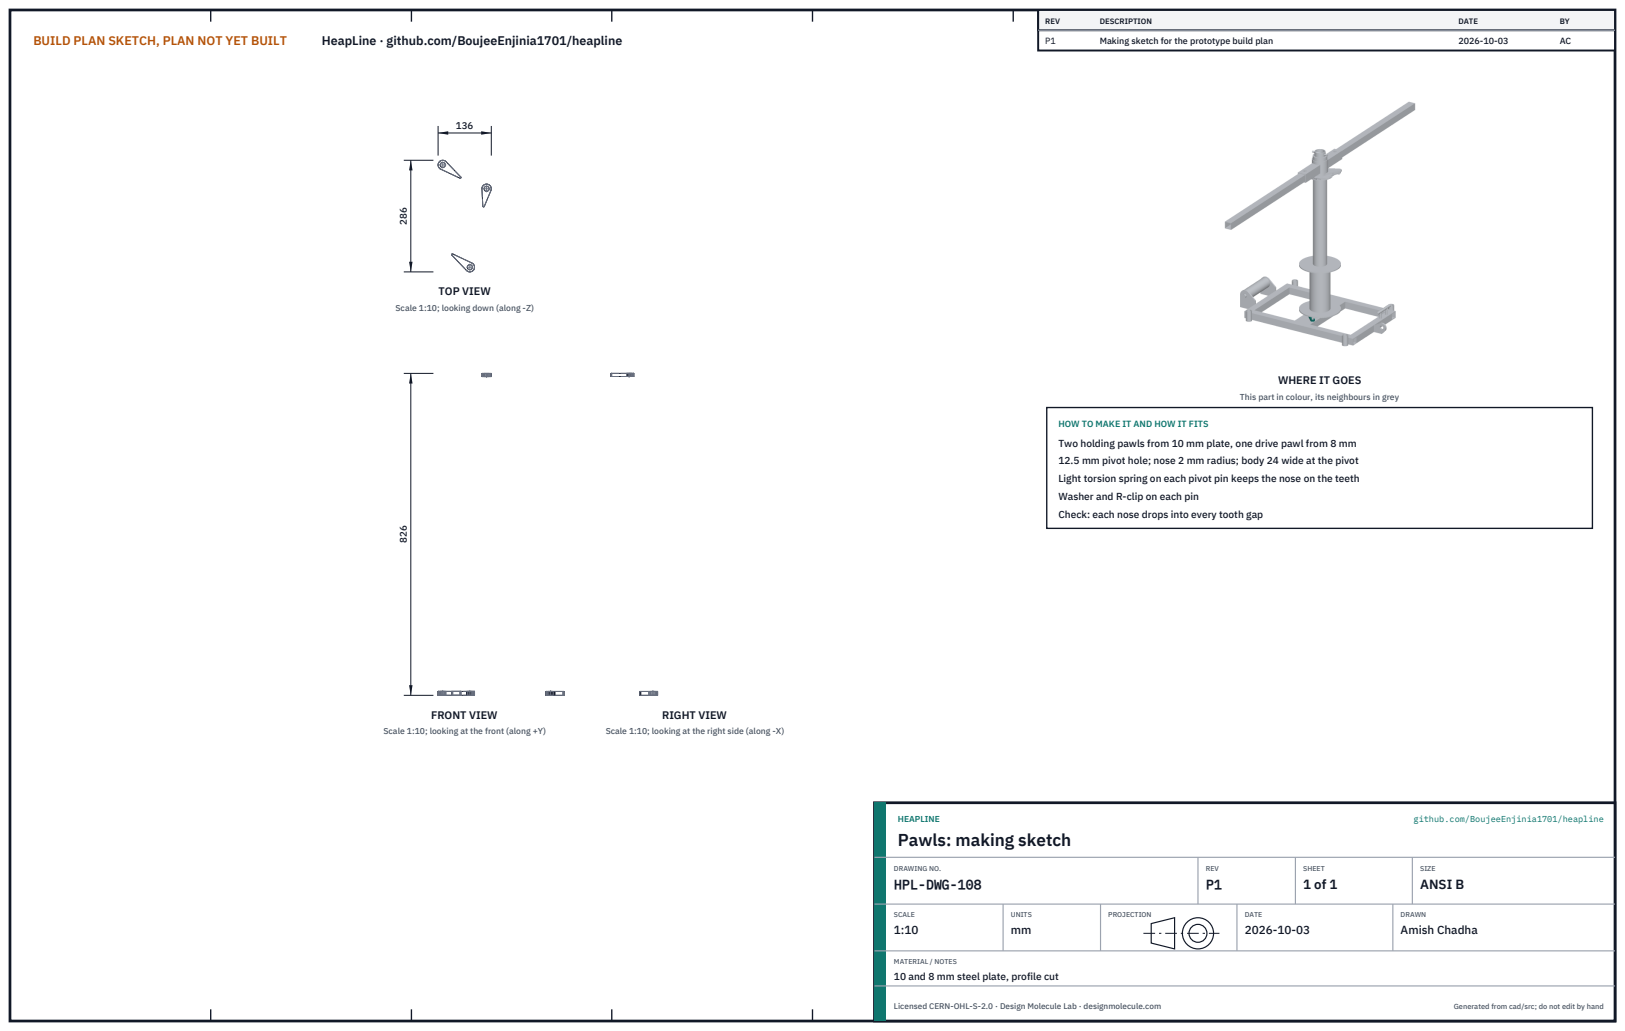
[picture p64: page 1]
BUILD PLAN SKETCH, PLAN NOT YET BUILT; HeapLine · github.com/BoujeeEnjinia1701/heapline; FRONT VIEW; TOP VIEW; RIGHT VIEW; REV; DESCRIPTION; DATE; Making sketch for the prototype build plan; HEAPLINE; github.com/BoujeeEnjinia1701/heapline; DRAWING NO. HPL-DWG-108; REV P1; SHEET 1 of 1; SIZE ANSI B; SCALE 1:10; UNITS mm; PROJECTION; DRAWN Amish Chadha; Licensed CERN-OHL-S-2.0 · Design Molecule Lab · designmolecule.com; Generated from cad/src; do not edit by hand

Scale 1:10; looking down (along -Z)

WHERE IT GOES

This part in colour, its neighbours in grey

HOW TO MAKE IT AND HOW IT FITS
Two holding pawls from 10 mm plate, one drive pawl from 8 mm
12.5 mm pivot hole; nose 2 mm radius; body 24 wide at the pivot
Light torsion spring on each pivot pin keeps the nose on the teeth
Washer and R-clip on each pin
Check: each nose drops into every tooth gap

Scale 1:10; looking at the front (along +Y)

Scale 1:10; looking at the right side (along -X)

Pawls: making sketch

MATERIAL / NOTES
10 and 8 mm steel plate, profile cut

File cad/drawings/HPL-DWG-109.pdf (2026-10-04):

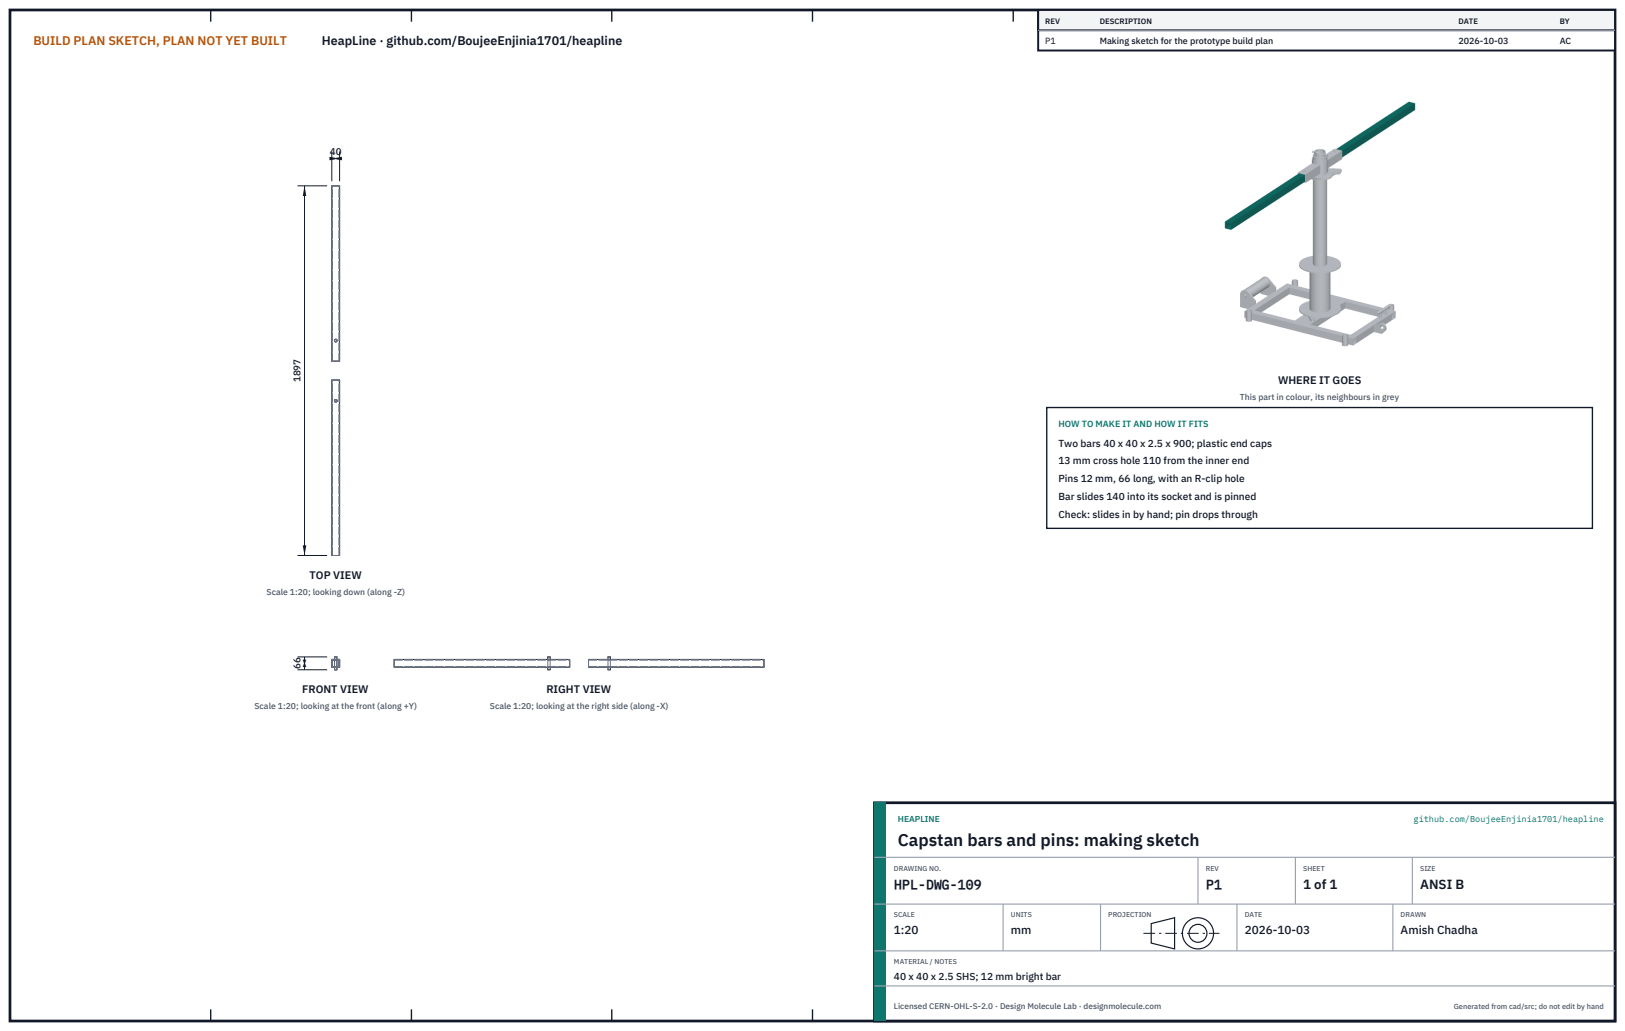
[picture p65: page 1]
BUILD PLAN SKETCH, PLAN NOT YET BUILT; HeapLine · github.com/BoujeeEnjinia1701/heapline; FRONT VIEW; TOP VIEW; RIGHT VIEW; REV; DESCRIPTION; DATE; Making sketch for the prototype build plan; HEAPLINE; github.com/BoujeeEnjinia1701/heapline; DRAWING NO. HPL-DWG-109; REV P1; SHEET 1 of 1; SIZE ANSI B; SCALE 1:20; UNITS mm; PROJECTION; DRAWN Amish Chadha; Licensed CERN-OHL-S-2.0 · Design Molecule Lab · designmolecule.com; Generated from cad/src; do not edit by hand

WHERE IT GOES

This part in colour, its neighbours in grey

HOW TO MAKE IT AND HOW IT FITS
Two bars 40 x 40 x 2.5 x 900; plastic end caps
13 mm cross hole 110 from the inner end
Pins 12 mm, 66 long, with an R-clip hole
Bar slides 140 into its socket and is pinned
Check: slides in by hand; pin drops through

Scale 1:20; looking down (along -Z)

Scale 1:20; looking at the front (along +Y)

Scale 1:20; looking at the right side (along -X)

Capstan bars and pins: making sketch

MATERIAL / NOTES
40 x 40 x 2.5 SHS; 12 mm bright bar

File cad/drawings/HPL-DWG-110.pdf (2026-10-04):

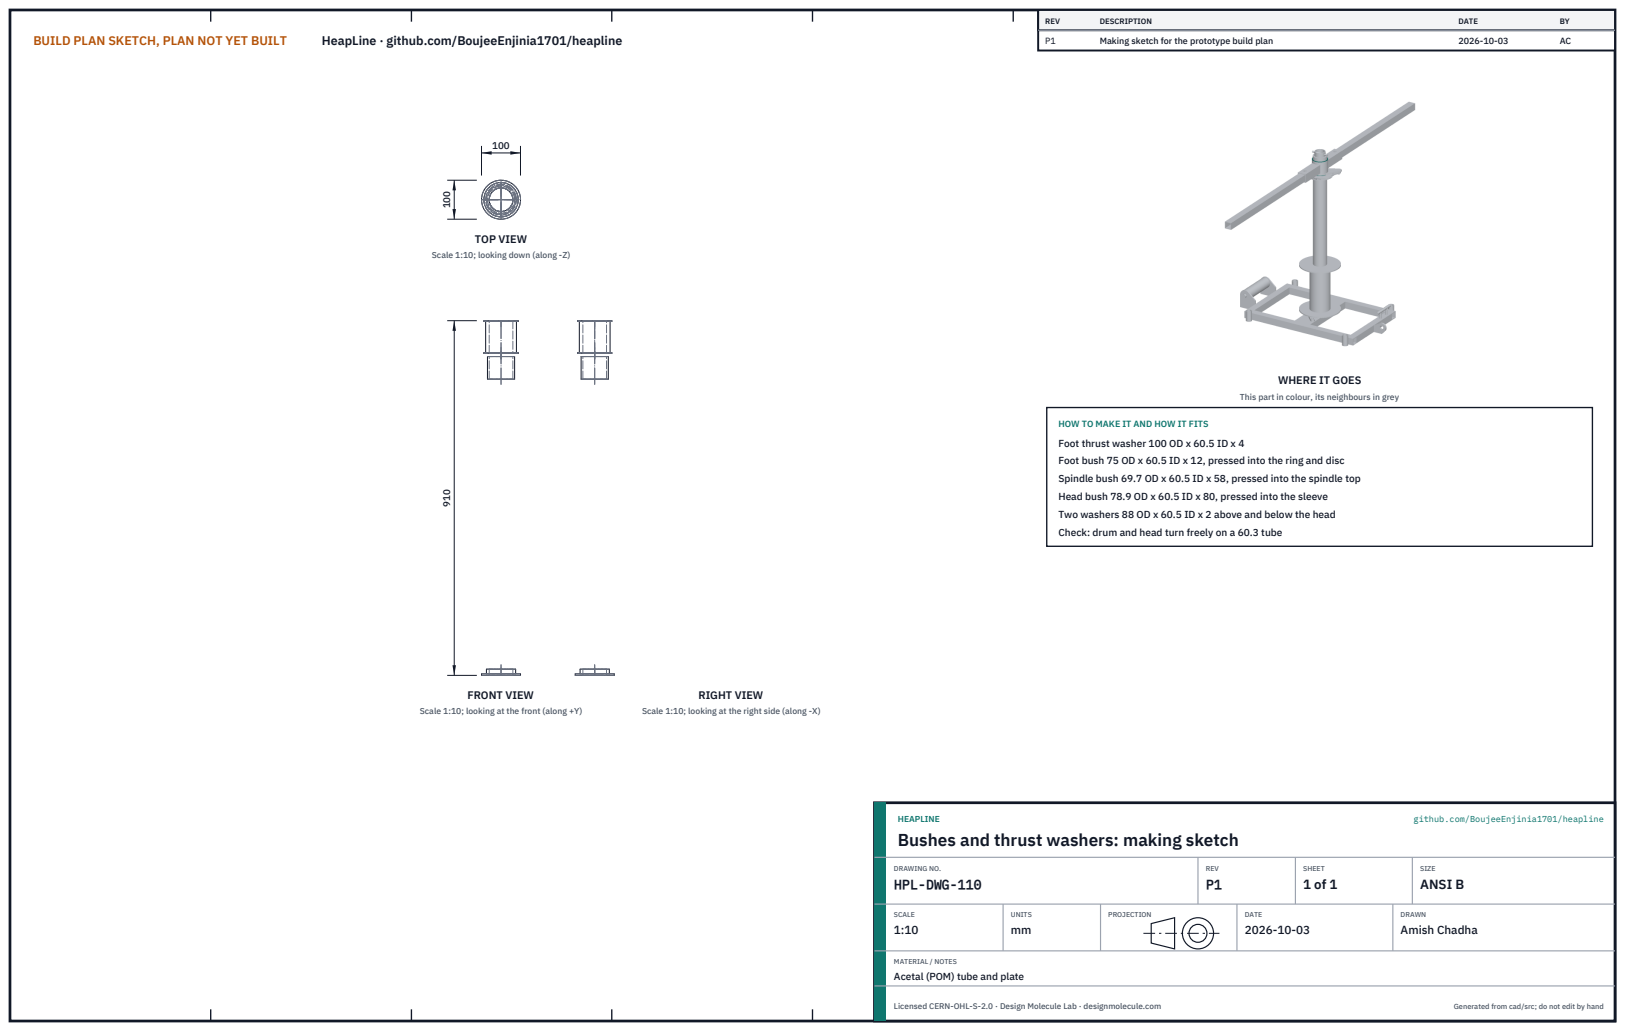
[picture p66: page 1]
BUILD PLAN SKETCH, PLAN NOT YET BUILT; HeapLine · github.com/BoujeeEnjinia1701/heapline; FRONT VIEW; TOP VIEW; RIGHT VIEW; REV; DESCRIPTION; DATE; Making sketch for the prototype build plan; HEAPLINE; github.com/BoujeeEnjinia1701/heapline; DRAWING NO. HPL-DWG-110; REV P1; SHEET 1 of 1; SIZE ANSI B; SCALE 1:10; UNITS mm; PROJECTION; DRAWN Amish Chadha; Licensed CERN-OHL-S-2.0 · Design Molecule Lab · designmolecule.com; Generated from cad/src; do not edit by hand

Scale 1:10; looking down (along -Z)

WHERE IT GOES

This part in colour, its neighbours in grey

HOW TO MAKE IT AND HOW IT FITS
Foot thrust washer 100 OD x 60.5 ID x 4
Foot bush 75 OD x 60.5 ID x 12, pressed into the ring and disc
Spindle bush 69.7 OD x 60.5 ID x 58, pressed into the spindle top
Head bush 78.9 OD x 60.5 ID x 80, pressed into the sleeve
Two washers 88 OD x 60.5 ID x 2 above and below the head
Check: drum and head turn freely on a 60.3 tube

Scale 1:10; looking at the front (along +Y)

Scale 1:10; looking at the right side (along -X)

Bushes and thrust washers: making sketch

MATERIAL / NOTES
Acetal (POM) tube and plate

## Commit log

2026-10-03 HeapLine at TRL 3: constructable design (kit 1.7.0)
    Problem, concept and requirements; sizing calculations; CAD model, STEP and STL; general arrangement drawing; bill of materials; build plan with making sketches, joint close-ups and step pictures; design decisions register (design choices decided under Amish's 2026-10-03 pre-approval; requirement decisions open for Amish); TRL 2 and TRL 3 review; photoreal renders and storefront card. Private until Amish opens it.
    [bom.csv, heapline-assembly.step, heapline-board.step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]
2026-10-04 Carry Amish's round 2 requirement decisions into the design
    Amish approved all 47 recommendations on 2026-10-03 ("i approve all of the 47 recommendations provided by you. Execute them."). Each repo gains a decision record (DDR-003, or the next free number for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
    [bom.csv, heapline-assembly.step, heapline-board.step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]
2026-10-04 Carry Amish's round-2 and round-3 decisions into the design
    Amish approved all 46 round-2 recommendations ("i agree with all the 46 recommendations you provided. please proceed.") and all round-3 recommendations ("For round 3, I agree with all your proposed r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
    [bom.csv, heapline-assembly.step, heapline-board.step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]
2026-11-05 Kit 1.9.1 upgrade: pipeline documents and detailed CAD for every option
    STEM check with fixes under the standing instruction and an independent
    review, concept options scored against the user requirements, URS, PRS,
    RTM, REG, FEA, RSK, MKT, PLN and DDR, every option modelled at D3 with
    cad/fidelity.json passing, and the concept options picture rendered with
    Blender Cycles on Amish's Mac. Concept choices stay proposed, awaiting
    Amish.
    Claude-Session: https://claude.ai/code/session_01LppsZSzPTJWTBAV5wh1Goq

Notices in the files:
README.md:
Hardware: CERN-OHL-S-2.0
